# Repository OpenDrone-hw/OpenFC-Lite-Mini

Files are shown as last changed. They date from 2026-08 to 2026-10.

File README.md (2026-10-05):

# OpenFC-Lite-Mini

Open source Betaflight flight controller built on the RP2354A, 20 x 20 mm
mounting pattern, part of the incutec OpenDrone line.

<p>
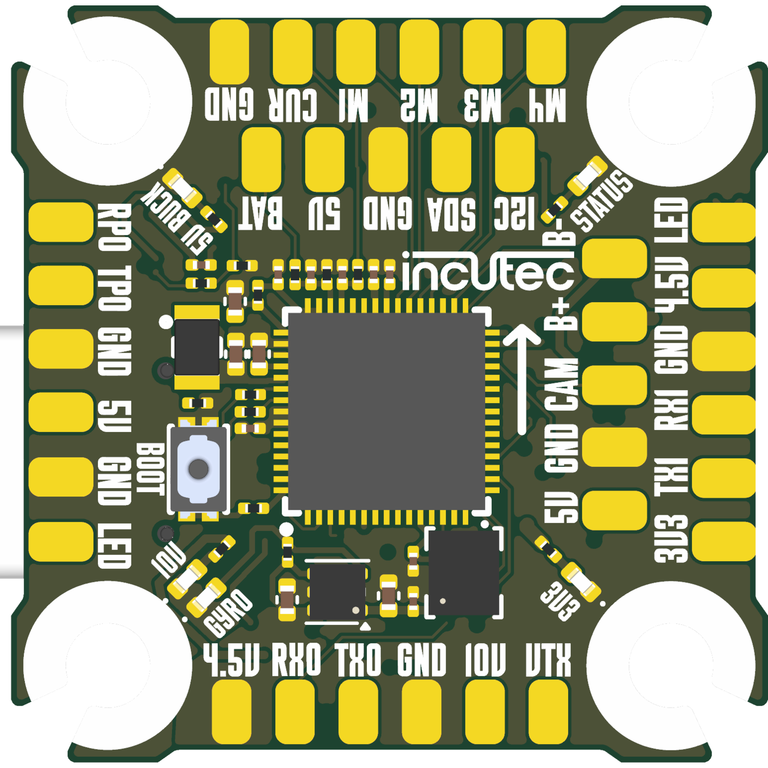
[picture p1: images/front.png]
OpenFC-Lite-Mini top

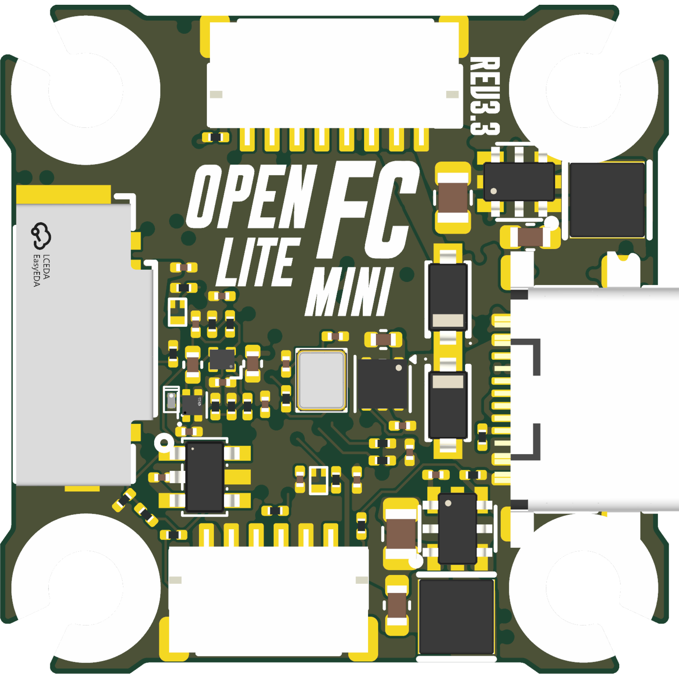
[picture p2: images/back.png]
OpenFC-Lite-Mini bottom

</p>







## Specifications

| | |
|---|---|
| Firmware | Betaflight |
| MCU | RP2354A |
| IMU | BMI270 |
| Barometer | None |
| Blackbox | microSD |
| OSD | Analog and digital |
| UARTs | 3 |
| Motor outputs | 4x DShot, bidirectional |
| RX | External, CRSF or SBUS |
| Input | 3-6S* LiPo (9.0-25.2 V) |
| BEC | 10 V switchable + 5 V always-on, 3 A |
| Current sense | Yes |
| USB | USB-C |
| Mounting | 20 x 20 mm, 3.0 mm holes |
| Dimensions | 26.9 x 26.9 mm |
| PCB | 6-layer, 1.6 mm |

* Also runs on 2S; the 10 V VTX output then follows the battery voltage instead of holding 10 V.

Technical write-up, part list and layout constraints: [AGENTS.md](AGENTS.md).

## In the line

What pairs with what, and what is available:
[opendrone.be](https://opendrone.be).

## Contributing

See [CONTRIBUTING.md](CONTRIBUTING.md).

## License

Hardware licensed under [CERN-OHL-S-2.0](https://ohwr.org/cern_ohl_s_v2.txt),
see [LICENSE](LICENSE).

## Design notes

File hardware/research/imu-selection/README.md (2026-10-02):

# IMU Selection Investigation: OpenFC-Lite-Mini Rev 2

**Superseded.** Rev 1 decision record, kept as history. The current IMU is the Bosch
BMI270 (U9), per the [README](../../../README.md) and [AGENTS.md](../../../AGENTS.md).

**Status:** superseded · **Started:** 2026-06-02

The Rev 1 IMU (ST **LSM6DSV16XTR**) is populated for development only. The Betaflight
team considers it unflyable; bench/flight data agrees. This folder collects datasheets
and test evidence to pick the **Rev 2 IMU**.

The footprint and its ST/TDK compatibility are described in
[`AGENTS.md`](../../../AGENTS.md) (Key parts section). IMU swap is a
part-population change once a part is chosen. Pin-by-pin verification against each
candidate family is in §8c below.

```
imu-selection/
├── README.md          ← this file (single source of truth for the investigation)
├── datasheets/        ← collected datasheets, named by part
└── (add scope captures, logs, FFTs here as they come in)
```

---

## 1. Hard requirements

| # | Requirement | Why |
|---|---|---|
| R1 | **Betaflight driver on current master** | No driver = no flyable firmware. Authoritative list below. |
| R2 | **Drops into LGA-14 (2.5×3 mm), pins 2/3 GND, 10/11 NC** | Existing footprint; pin-1 orientation must match. |
| R3 | **Flyable**: low in-band gyro noise, robust to electrical + vibration noise | The whole reason DSV16X is being replaced. |
| R4 | **Sourceable at volume** | Selling the board. |
| R5 | **Low cost**, to keep the "Lite" price point | The IMU is a large share of BOM cost. |
| R6 | **VDDIO works at 1.8 V analog / 3.3 V IO** | Board runs IMU off +1.8V_GYRO (U6 NCV8187) + 3.3V IO. |

A part failing R1 or R2 is out unless someone commits to adding the driver / reworking the
footprint.

---

## 2. Betaflight supported-IMU list (authoritative)

From `drivers/accgyro/accgyro.h` (`gyroHardware_e`) + `sensors/acceleration.h` on current
master. **Only these have flyable drivers today.**

- **InvenSense MPU:** MPU6000, MPU6050, MPU6500, MPU9250
- **InvenSense ICM-206xx:** ICM20601, ICM20602, ICM20608G, ICM20649, ICM20689
- **InvenSense ICM-426xx / 40609:** ICM42605, **ICM42688P**, **ICM42622P**, ICM42686P, ICM40609D
- **InvenSense IIM industrial (426xx driver):** IIM42652, IIM42653
- **InvenSense ICM-456xx:** ICM45605, **ICM45686**
- **Bosch:** BMI160, **BMI270**
- **ST:** LSM6DSO, **LSM6DSV16X**, **LSM6DSK320X**, L3GD20 (gyro-only)
- **Virtual:** SITL/HITL

**NOT on master (would need a driver):** ICM-56686 (RPi is adding it, not merged),
BMI323, BMI088, ICM-42670-P, LSM6DSV320X (the *V* high-g, ≠ the *K*).

---

## 3. Candidate matrix

"BF" = on master. Footprint column
flags anything that isn't a clean drop-in.

| Part | BF | Footprint | Gyro noise mdps/√Hz | Verdict |
|---|---|---|---|---|
| **ICM-42688-P** | ✓ king | LGA-14 2.5×3 ✓ | **2.8** | Best-flying, high cost |
| **ICM-42622P** | ✓ | LGA-14 ✓ | ~2.8 (class) | strong reports |
| **IIM-42652** | ✓ | LGA-14 ✓ | 3.8 | Industrial temp, high cost |
| **ICM-45686** | ✓ | **LGA-14 3×2.5** ⚠ rotated | ~ | Newer; verify pin-1, high cost |
| **ICM-45605** | ✓ | LGA-14 | - | budget 456xx |
| **ICM-42605** | ✓ | LGA-14 2.5×3 ✓ | (class) | **Supported: solid fallback** |
| **BMI270** | ✓ | LGA-14 2.5×3 | 7 (perf) | **Low cost, only AC-PSRR spec'd** ⚠ verify Bosch pinout |
| **LSM6DSO** | ✓ | LGA-14 2.5×3 ✓ | (older) | low cost, older gen |
| **LSM6DSV16X** | ✓ | LGA-14 2.5×3 ✓ | 2.8 | **Rev 1 part: unflyable, replaced** |
| **LSM6DSK320X** | ✓ | LGA-14 2.5×3 ✓ | **3.8** | BF/STM target; **not orderable**, samples gated |
| ICM-56686 | ✗ | LGA-14 2.5×3 | 2.9 | No BF driver yet (RPi adding); 29.3kHz MEMS |
| BMI323 | ✗ | LGA-14 | - | No BF driver; Bosch filters undocumented |
| BMI088 | ✗ | **LGA-16 3×4.5** ✗ | 14 | No driver, wrong footprint, 2.4V floor: out |
| LSM6DSV320X | ✗ | LGA-14L | - | *V* variant, no BF driver (≠ DSK) |

---

## 4. Datasheet spec comparison

Mined from the PDFs in `datasheets/`. "n/s" = not specified in datasheet.

| Spec | ICM-42688-P | IIM-42652 | ICM-56686 | BMI270 | BMI088 | LSM6DSV16X | LSM6DSK320X |
|---|---|---|---|---|---|---|---|
| Gyro noise (mdps/√Hz) | **2.8** | 3.8 | 2.9 / 2.5(20b) | 7 / 10 | 14 | **2.8** | 3.8 |
| Accel noise (µg/√Hz) | 65/70 | 70 | 55/70 | 160 | 190 | 60/100 | 60/100/1000(hi-g) |
| Gyro FS max (dps) | 2000 | 2000 | 4000 | 2000 | 2000 | 4000 | 4000 |
| Accel FS max (g) | 16 | 16 | 32 | 16 | 24 | 16 | **320** (hi-g) |
| Max gyro ODR (kHz) | 8 | 8 | 6.4 | 6.4 | 2 | 7.68 | 7.68 |
| MEMS resonant freq | n/s | n/s | **29.3 kHz** | n/s | n/s | n/s | n/s |
| Anti-alias filter | AAF 42-3979Hz + notch | AAF 42-3979Hz | AAF+LPF | LPF | LPF 5-532Hz | analog AAF + LPF1 | analog AAF + LPF1 |
| VDD / VDDIO (V) | 1.71-3.6 / 1.71-3.6 | 1.71-3.6 / 1.71-3.6 | 1.71-3.6 / 1.08-3.6 | 1.71-3.6 / 1.2-3.6 | **2.4**-3.6 / 1.2 | 1.71-3.6 / 1.08 | 1.71-3.6 / 1.08 |
| SPI max (MHz) | 24 | 24 | 24 | 10 | 10 | 10 | 10 |
| Package | LGA-14 2.5×3 | LGA-14 2.5×3 | LGA-14 2.5×3 | LGA-14 2.5×3 | **LGA-16 3×4.5** | LGA-14 2.5×3 | LGA-14 2.5×3 |
| **PSRR / supply-noise spec** | 10mVpp tol. | 10mVpp tol. | 10mV typ/50max, to 1MHz | **AC PSRR: gyro 0.40dps/50mV, accel <8mg/50mV, 100Hz-1MHz** | DC drift only | **n/s** | **n/s** |
| CLKIN | **yes** 31-50k | **yes** | **yes** 20-40k | no | no | no | no |

### Headline findings

1. **The DSK320X is NOT a quieter gyro than the DSV16X.** On paper it's *worse*: 3.8 vs
   2.8 mdps/√Hz, identical accel noise. Neither ST datasheet documents a MEMS resonant-freq
   change or sensor-level vibration-immunity improvement. The DSK's only vibration-relevant
   edge is the **±320 g high-g channel** (clip resistance under hard impact) + quad-channel
   UI/EIS/OIS/high-g filtering, **not** a lower-noise or more supply-robust gyro core. This
   directly contradicts the framing that the DSK "fixes the noise": the fix, if real, is in
   MEMS hardware ST does not document, or in the high-g anti-clip path.

2. **Neither ST part specs any PSRR / supply-noise rejection.** This is the standout gap
   versus the observed failure (sensitivity to *electrical* noise). You cannot design a
   supply-ripple budget against a number that doesn't exist.

3. **BMI270 is the only candidate with a frequency-resolved AC PSRR:** gyro 0.40 dps per
   50 mV ripple (100 Hz-1 MHz). InvenSense parts at least give a max-tolerable-ripple (10 mV).
   If supply-coupled noise is the real culprit, Bosch + InvenSense give you a spec; ST gives
   you nothing.

4. **Vibration-aliasing immunity:** ICM-56686 is the only part publishing a MEMS drive
   frequency (29.3 kHz, far above any propwash band, good anti-alias margin). BMI088 is the
   only one with explicit "drone/robotics vibration suppression + ±24 g anti-clip" language,
   but it's the worst on noise, wrong footprint, no driver. Out on R1/R2.

---

## 5. External input and flight data

### Betaflight-ecosystem consensus
- LSM6DSV16X is considered **unflyable**: "too sensitive to electrical noise." Tested on
  5+ FCs across brands, all unacceptable; it will not be approved for ecosystem hardware.
- **LSM6DSK320X** is the recommended successor, developed together with ST; mass
  production targeted **June 2026**. Described as worth waiting for, drop-in on the LSM16
  design.
- **ICM-42688 "still king"** but TDK supply is hard. **ICM-42622 also rated very highly.**
- **Bosch** BMI270: internal filters undocumented, "not great but cheap and works",
  pin-for-pin swappable later. Recommended only as a cheap interim.
- **Clone IMUs** (HXY ICM-42688P etc.) rejected on principle: unknown provenance.
- ⚠ Bias to note: Betaflight and ST have a working relationship, and ST has a commercial
  interest in the DSK320X winning the comparison. Weigh accordingly.

### Counter-argument: the failure may be PDN-specific
- This board's IMU supply is unusually good: **NCV8187 ~90 dB PSRR**, and running the IMU
  at **1.8 V** means a large LDO dropout → even better rejection. The board's electrical
  environment is likely *better* than the cheap FCs the DSV16X was condemned on, so those
  failures may be PCB/PDN-specific, not intrinsic to the part. (For comparison, at least
  one well-regarded reference design uses a ~75 dB PSRR IMU LDO, worse than ours.)
- DSK320X has **different MEMS hardware**. DSV320X is the *V* high-g variant.
- One proposed strategy: ship the Lite with **BMI270** (cheap, holds the price point) now;
  a premium board with a higher-end IMU later.

### Flight data: hover A/B against an ICM reference board
- Our board (DSV16X): **prefilter gyro shows ~20 dB more <100 Hz broadband noise** than an
  ICM reference board, on a *hover* test. Would need a hard detune to fly.
- Comparison is apples-to-apples: both FCs MCU-down, gyro-up → noise is **not** ESC-side.
- **Adding a cap on 5 V** often helps in this failure mode → points at supply-coupled noise.
- ⚠ Counter-datapoint: a 1408/3750kv/6S 3" test quad on DSV16X flew **perfectly** once a
  suitable tune/filter preset was applied, i.e. the issue may be tune/filtering, not raw
  sensor. Sample size 1. Worth resolving before committing.

### ICM-56686
- Betaflight support for the **ICM-56686** (positioned as an ICM-42688 alternative) is
  reportedly in development elsewhere; **no driver on master yet**. TDK cleared the
  datasheet for sharing → in `datasheets/`.

---

## 5b. What actually matters in FPV (not bench noise density)

FPV is not a clean environment: the gyro lives in heavy mechanical vibration (motors, props,
frame/arm resonances, often 0.5-4 kHz) plus ESC switching/EMI. **Bench noise density is nearly
the wrong figure of merit.** Proof: the DSV16X has the *best* noise density of every candidate
here (2.8 mdps/√Hz, tied with the 42688) and is still unflyable. Flyability is set by how the
part handles **out-of-band energy**, not its quiet-room floor:

1. **Vibration rectification / aliasing.** Out-of-band vibration (kHz) folds into the control
   band as a DC offset shift + low-frequency broadband, exactly the **<100 Hz broadband**
   signature in the hover A/B data (§5). Governed by the **MEMS drive/sense resonant frequency** and
   the **analog anti-alias filter ahead of the ADC** (not the digital LPF, which is too late).
   → ICM-56686 is the only part publishing its resonant freq (29.3 kHz, big margin). ST parts
   publish neither resonant freq nor rectification behavior.
2. **Clipping headroom under vibration.** Instantaneous rate/accel spikes that exceed FS clip,
   and clipping rectifies into DC + harmonics. This, not "more range", is why DSK320X has a
   ±320 g accel channel and BMI088 has ±24 g. A ±16 g accel can saturate on a rough quad.
3. **Supply / EMI rejection.** ESC switching coupling into a part with unbounded PSRR. ST specs
   none; BMI270 specs AC PSRR; InvenSense specs a max tolerable ripple.

**Consequence for this investigation:** rank candidates on (1) anti-alias/resonant-freq margin,
(2) clip headroom, (3) PSRR, and above all on **empirical flight/blackbox data**, since
datasheets barely document any of the three. The noise-density column in §4 is informational,
not a selection criterion. This is why BF qualifies gyros by flying them, and why a
worse-on-paper part (DSK320X) can outfly the DSV16X.

## 5c. Prior diagnostic campaign, firmware A/B builds (sister board)

A documented DSV16X diagnostic effort already ran on a sister board carrying the same
LSM6DSV16XTR (late April 2026): one firmware variant per hypothesis, each with a blackbox
test plan. Results live in the blackbox logs, still to be recovered.

| Firmware change | Hypothesis | Symptom targeted |
|---|---|---|
| DRDY PULSED→LATCHED | RP2350 @150 MHz EXTI+SPI-DMA latency exceeds the **75 µs DRDY pulse** under heavy IRQ load (PIO DSHOT/UART, SD blackbox) → missed gyro samples → sample-rate drift | **200 Hz oscillation under throttle, fine at hover** |
| accel LPF2 250 Hz→~22 Hz | motor-harmonic vibration >250 Hz leaks into accel → corrupts IMU-fusion gravity vector | **"gravity-vector wandering" in ANGLE mode** |
| on-board chirp PID identifier (`USE_SYSID`) | (tooling) `sysid raw` emits a versioned **FRF CSV** for frequency-response analysis | n/a |

**Why this matters for IMU selection:** the two leading in-house hypotheses for the DSV16X
misbehaviour are **firmware/platform**, not "bad MEMS":
1. a **DRDY timing bug specific to RP2350 under load** (missed samples → the 200 Hz throttle
   oscillation), and
2. an **accel-filter config** leaking vibration into fusion (gravity wander).

Both are fixable without changing the sensor. This strongly reinforces §6: the part may be
partly mis-integrated on RP2350, not intrinsically unflyable. Note these symptoms (200 Hz
under-throttle oscillation; gravity wander) are **distinct from the hover A/B** result (<100 Hz
broadband prefilter noise at hover), so there may be ≥2 independent problems, only one of
which the sensor swap would fix.

The blackbox logs from these builds plus their baseline, and the `sysid raw` FRF CSV, are
the highest-value missing evidence (see §8).

## 5d. RESOLVED on the sister board, empirical

The firmware A/B campaign concluded the DSV16X problem is **not firmware-fixable**: it's a MEMS
hardware property. The sister board's firmware config records the swap rationale: the
LSM6DSV16XTR was found to have a **MEMS resonance vulnerability in the ~25 kRPM motor band**
on that airframe (the internal gyro **saturating from acoustic/vibration energy at the
resonator's drive frequency, producing bursts of false rotation reads up to chip full-scale
±2000 dps**). Swapping to the **ICM-42688-P** (drop-in pin-compatible, confirmed by multiple
BF targets that support both chips on the same pads) **eliminated the resonance issue**, and
the sister board's next PCB revision is designed with the ICM-42688-P only.

**What this settles, and what it does NOT.**

Settled: **swapping to ICM-42688-P made the board flyable**, and the sister board's next
revision standardizes on it. That's a solid empirical result for *part selection*.

NOT settled: the **root cause**. The "MEMS resonance in the ~25 kRPM band" wording is a
*hypothesis writeup*, not a measured result, and it does not survive scrutiny as a single cause:

- **The hover A/B noise is <100 Hz broadband at HOVER** (low RPM/vibration). A high-RPM resonance
  should be throttle-dependent and absent at hover, which is what the *diag build* describes
  ("200 Hz under throttle, fine at hover"). So there are **≥2 distinct symptoms**, not one.
- **"~25 kRPM band" is physically shaky:** 25 kRPM ≈ 417 Hz fundamental; a MEMS gyro drive
  resonance is ~20-25 **kHz** (~50× higher). 417 Hz vibration doesn't excite a 20 kHz drive
  mode directly. The plausible mechanism is **aliasing** (out-of-band energy folding in through
  an inadequate AAF), a filtering/architecture issue, not "resonator saturation."
- **"5 V cap helps" + the "electrical noise" reports + ST publishing no PSRR** → an independent
  **supply/PSRR** contributor.
- **A tune/filter preset made one build fly perfectly** → **tune/filtering** is a large lever; a
  hard MEMS-saturation defect wouldn't yield to a preset.
- **The ICM swap is a confounded experiment:** it changed sensor + driver maturity + AAF/notch
  behavior + CLKIN jitter removal simultaneously. It does **not** isolate resonance as the cause.

**Working model: multi-causal**, at least: (1) anti-alias/filtering inadequacy → aliased
broadband; (2) supply/PSRR sensitivity; (3) RP2350 DRDY/sample-timing under load; (4) MEMS
resonance/clipping at high vibration; (5) driver/tune immaturity. The ICM-42688-P is better on
*several* of these at once, which is why it works, but the dominant factor is not isolated.

**Consequence for selection:** because the win is partly filtering/driver/PSRR (not purely a
MEMS-element property), a same-family ICM-42605 is a *strong* bet (shares AAF+notch+driver), and
the **BMI270's real AC-PSRR spec regains relevance** if supply coupling is a major contributor.
Only the actual logs/FFT (hover vs throttle, ± a supply-ripple injection test) can decompose it.

## 6. Working hypothesis

The DSV16X's in-flight noise is most plausibly **supply/electrical-coupling + tune**, not a
raw-noise-density deficit (its density spec is best-in-class, tied with the 42688). Evidence:
- 20 dB excess is **broadband <100 Hz** = classic aliased/rectified noise, not white density.
- "Adding a cap on 5 V helps" + "sensitive to electrical noise" = PDN/supply path.
- A good preset made it fly fine on our board (better PDN than the FCs BF condemned).
- ST publishes **no PSRR**, so the part's supply robustness is genuinely unknown/unbounded,
  consistent with it being fragile on noisy boards even if fine on a clean one.

This means the decision is partly **political** (BF approval / the 180-brand ecosystem rejects
DSV16X regardless of our data) and partly **technical** (what actually flies clean on *our*
PDN). Those can have different answers.

---

## 7. Decision options

**Reframed by §5d:** the failure is MEMS resonance saturation, and **ICM-42688-P is the
empirically proven fix** on the sister board. The 426xx family shares the same gyro sense-element
architecture, so a cheaper family member is the *likely*, but not yet proven, way to keep the
fix at a Lite price. A different-MEMS part (BMI270) is now a real risk, not a safe interim.

- **A: ICM-42688-P (proven). ← lowest technical risk.** The exact part that eliminated the
  resonance on the sister board, whose next revision standardizes on it. Drop-in (§4), uses wired CLKIN (GPIO15).
  **Cost is the only problem:** too expensive for the "Lite"
  price point. Right call for a *premium* OpenFC; painful for Lite.
- **B: ICM-42605 (cheap same-family bet). ← leading for Lite (2026-06-02).** Same 426xx gyro
  architecture as the 42688 → *most likely* shares the resonance immunity (same sense element,
  different binning/noise grade). BF-supported, lower cost, clean
  2.5×3 footprint, uses the wired CLKIN. **Risk: the resonance immunity is not yet confirmed on
  the 42605 specifically**: verify by flying it (it shares the 42688 driver, so it's a config
  one-liner: `USE_GYRO_SPI_ICM42605`). If it holds, this is the answer for Lite.
- **C: ICM-42622P** (highly rated, same family), but out on cost and availability
  at the time.
- **D: BMI270 (cheapest, now higher risk).** Lowest cost, BF-supported, footprint
  drop-in (§7b), only candidate with a real AC-PSRR spec. **But:** different Bosch MEMS: we now
  know the DSV16X failure was MEMS-resonance, and there is **no evidence BMI270 survives this
  airframe's resonance band**. Bench noise density (7) is irrelevant (§5b); the resonance
  question is not. Only choose if 42605 also fails and price dominates, and flight-test it
  against the same airframe first.
- **E: DSK320X**, BF/STM blessed, drop-in, but **not orderable** (samples gated), and per §4
  not a lower-noise gyro. Track for the premium SKU; not actionable for Rev 2 now.
- **F: Two-SKU strategy.** Premium OpenFC = ICM-42688-P (proven). Lite = ICM-42605 if it flies
  clean, else BMI270 as the cost-floor fallback. Aligns the premium board with the sister board's next revision.

**Recommendation:** Lite-Mini Rev 2 → **ICM-42605** (lower cost, same family as the proven
fix, wired CLKIN usable), with **ICM-42688-P** as the drop-in premium/no-compromise option on the
identical footprint. **Flight-test the 42605 against a ~25 kRPM-band airframe before committing**:
that's the one open risk, and it's cheap to close.

---

## 7b. BMI270 footprint verification (DONE 2026-06-02)

Checked BMI270 pinout vs the actual board net on U9 (netlist export of `OpenFC.kicad_sch`).
Board pins wired for the LSM6DSV16X: 1 MISO, 2 GND, 3 GND, 4 INT, 5 +3.3V, 6 GND, 7 GND,
8 +1.8V_GYRO, 9 CLKIN(GPIO15), 10 NC, 11 NC, 12 CS, 13 SCK, 14 MOSI.

**BMI270 is a drop-in, with two caveats:**
- **Pins 2/3 = ASDx/ASCx (aux/OIS), hard-grounded on our board.** Bosch documents "VDDIO or
  DNC", *not* GND. The shared 20×20 FC footprint grounds these and BMI270 ships on it across
  many BF boards (works empirically), but it is **outside Bosch's stated spec**: verify on a
  sample; worst case a DNC cut on 2/3.
- **Pin 9 = our CLKIN net (GPIO15).** On BMI270 pin 9 is INT2 (no clock input). No regression
  (ST part also has no CLKIN); just don't drive a clock on GPIO15 in firmware. Aligns with the
  Rev 2 "drop CLKIN" plan.
- All other pins (SPI 1/12/13/14, VDD 8 @1.8V, VDDIO 5 @3.3V, INT1 4, GND 6/7, NC 10/11) match 1:1.

## 8. Verification state

- **Verified:** BMI270 LGA-14 fits the existing footprint. Pins 2/3 remain an
  out-of-spec, field-proven grounding caveat; pin 9 maps CLKIN to unused INT2.
- **Not evidenced here:** ICM-45686 land-pattern orientation; availability of
  ICM-42622P or LSM6DSK320X; and ICM-56686 driver maturity.
- **Design-dependent:** CLKIN is useful for the listed TDK parts and unused by
  the ST and Bosch candidates. Its routing follows the selected IMU.
- **Not present in this repository:** the source FFT/blackbox data behind the
  hover comparison, a cross-board PDN comparison, and measured 1.8 V rail
  compatibility for every candidate. Claims depending on those data are not
  treated as verified.

---

## 8b. Log comparison: PIDtoolbox method + first run (2026-06-02)

**How PIDtoolbox (PTB) works** (Brian White / bw1129, MATLAB or compiled standalone):
decodes BF blackbox → modules: **Spectral Analyzer** (gyro/dterm PSD in dB + **Freq×Throttle
spectrogram**), **Step Response** (setpoint→gyro deconvolution), time-domain plots.
- Set **`debug_mode = GYRO_SCALED`** so unfiltered gyro is logged (PTB then shows *gyro prefilt*
  vs *gyro*, and computes filter phase latency). **Modern BF (2026.x) logs `gyroUnfilt[]`
  natively** regardless of debug_mode, our logs have it, so prefilter analysis works anyway.
- Log at **2 kHz** (spectrograms reach ~1 kHz). Fly **throttle sweeps** (idle→full over 5-10 s, ×2-3).
- **Reading Freq×Throttle:** diagonal line rising with throttle = **motor noise (tracks RPM)**;
  horizontal line at fixed Hz = **frame resonance or electrical (throttle-independent)**;
  <20 Hz = real craft movement (ignore for noise); 20-100 Hz should be quiet (propwash/tune).
- **Bad-gyro test:** one axis much noisier <200 Hz; rotate FC 90°: if the noisy axis follows, gyro suspect.

**Why prefilter (`gyroUnfilt`) is the right signal here:** it's the raw sensor before BF's filter
stack, so comparing it removes the filter-tune confound and isolates the *sensor*.

**Reproduce without MATLAB:** `analysis/compare_gyro.py LOG_A.csv LOG_B.csv labelA labelB`
(numpy/scipy/matplotlib) emits `psd_overlay.png`, `spectrogram_<label>_<axis>.png`, and a
band-RMS table. PTB GUI crashed on macOS 2026-06-02; this is the fallback + it's repo-committed.

**First run: LOG00083 vs LOG00090** (both built for OPENFC_ECO, the OpenFC-ECO-era firmware target since superseded by OPENFC_LITE_MINI_RP2350A; BF 2026.6.0-alpha, 8 kHz loop, logged
≈1.88 kHz → 940 Hz Nyquist). **Inconclusive on sensor, the pair is not controlled:**
- LOG83 = 135 s full sweep, gyro LPF off; LOG90 = **only 6 s**, sparse throttle, dyn-LPF 250/500.
- **Which log is which sensor is unknown** (BF header doesn't name the gyro; same firmware hash
  runs either chip via autodetect). **The LOG#→sensor mapping must be recovered from test notes.**
- Prefilter PSD floors **nearly overlap** in the noise-dominated bands (motor hump ~200-400 Hz,
  >400 Hz). The big 0-20 Hz "RMS" differences are **flight movement, not noise** (135 s aggressive
  vs 6 s), not a sensor signal.
- LOG83 spectrogram = **clean, healthy**: motor band tracks throttle, no fixed horizontal lines,
  no saturation bursts. LOG90 looks hotter in 200-500 Hz but is too short/sparse to trust.

**Verdict:** these two logs cannot decide DSV16X vs ICM. Need a **matched pair**: same craft,
both throttle sweeps, ≥30 s each, same filter config (or compare prefilt only), and a known
LOG#→sensor map. Then the Freq×Throttle + prefilt-PSD overlay will show whether the DSV16X has
(a) RPM-tracking diagonal excess (vibration/alias), (b) fixed-Hz lines at idle (electrical/PSRR),
or (c) saturation bursts (resonance/clipping), decomposing §5d's multi-causal model.

## 8c. Universal drop-in verification (footprint + nets, working tree 2026-06-03)

Footprint `lib:LGA-14_L3.0-W2.5-P0.50-BR`. U9 net map (current schematic): 1 MISO · 2 GND ·
3 GND · 4 INT · 5 +3.3V(VDDIO) · 6 GND · 7 GND · 8 +1.8V_GYRO(VDD) · 9 CLKIN(GPIO15) ·
10 NC · 11 NC · 12 CS · 13 SCK · 14 MOSI. Checked against datasheet pinouts:

| Pin | Board net | ST LSM6D* (DSV16X / DSK320X / DSO) | TDK ICM-426xx / IIM-426xx | Bosch BMI270 |
|---|---|---|---|---|
| 1 | MISO | SDO ✓ | AP_SDO ✓ | SDO ✓ |
| **2** | **GND** | SDx: *"VDDIO or GND"* ✓ | RESV: *NC/GND* ✓ | ASDx (aux, unused→input): table prefers *VDDIO/DNC*, GND benign ✓ |
| **3** | **GND** | SCx: *"VDDIO or GND"* ✓ | RESV: *NC/GND* ✓ | ASCx (aux, unused→input): GND benign ✓ |
| 4 | INT | INT1 ✓ | INT1 ✓ | INT1 ✓ |
| 5 | +3.3V | VDDIO ✓ | VDDIO ✓ | VDDIO ✓ |
| 6 | GND | GND ✓ | GND ✓ | GNDIO ✓ |
| 7 | GND | GND ✓ | RESV→GND ✓ | GND ✓ |
| 8 | +1.8V | VDD ✓ | VDD ✓ | VDD ✓ |
| 9 | CLKIN | INT2 (idle, ok)¹ | INT2/FSYNC/**CLKIN** ✓ (uses it) | INT2 (idle, ok)¹ |
| 10 | NC | OCS_Aux NC ✓ | RESV NC ✓ | OCSB DNC ✓ |
| 11 | NC | SDO_Aux NC ✓ | RESV NC ✓ | OSDO DNC ✓ |
| 12 | CS | CS ✓ | AP_CS ✓ | CSB ✓ |
| 13 | SCK | SCL/SCLK ✓ | AP_SCLK ✓ | SCK ✓ |
| 14 | MOSI | SDA/SDI ✓ | AP_SDI ✓ | SDI ✓ |

¹ pin 9 = INT2 on ST/Bosch; harmless as long as firmware does not drive a clock on GPIO15.

### Verdict: pins 2/3 at GND are fine for all; footprint is universal
The board grounds pins 2/3. For an **unused** aux interface this is correct/benign across all families:
- **ST LSM6D\*** (DSV16X / DSK320X / DSO): datasheet sanctions pins 2/3 → "VDDIO **or GND**". ✓
- **TDK ICM-426xx/IIM and ICM-456xx/56xx-gen** (confirmed from ICM-56686 pinout: pins 2/3/10/11 =
  RESV/AUX1, pin 9 = INT2/FSYNC/CLKIN, same universal layout): RESV = "NC **or GND**". ✓
- **Bosch BMI270: GND is safe (mechanism verified in datasheet, 2026-06-03):** aux/OIS is disabled
  by default (`PWR_CTRL.aux_en=0`; BF never enables it for a bare gyro), so ASDx/ASCx are **high-Z
  inputs**: nothing drives them, GND = no contention. The only "pull-up" is a *configurable* internal
  pull-up on ASDA (`AUX_IF_TRIM.asda_pupsel`: off/40k/10k/2k) used for the aux-I2C SDA line; inactive
  when aux is off (worst case a 40k pull → ~80 µA to GND, harmless). Bosch's "VDDIO or DNC" is
  conservative guidance for the aux-*enabled* case; it does **not** mean GND damages the part. Bosch's
  own power-off note even says interface pins "must be kept close to GNDIO potential." The *only*
  failure case is firmware enabling the aux **I2C master** (ASCx becomes a driven clock → GND short),
  which BF does not do. **GND is the correct universal tie** (VDDIO fails TDK RESV; NC fails ST's
  "needs a level"). One firmware caveat: never enable the BMI270 aux interface.

**So the footprint is a genuine universal drop-in** for every ST LSM6D\*, every TDK ICM-426xx/IIM,
the 456xx/56xx-generation TDK parts, and the BMI270: **no schematic change needed.**

### Open item
- **ICM-45686/45605 physical orientation:** pin *functions* match (per 56686), but the 45686 is listed
  as LGA-14 **3×2.5** vs our 2.5×3 → check body/pin-1 rotation against the footprint before
  committing. (Functional pinout is fine; this is purely a package-outline check.)
- **Keep pin 9 (GPIO15→CLKIN) wired**: revisit the Rev 2 "drop CLKIN" note. Harmless for ST/Bosch
  (INT2, idle), and gives TDK 426xx/456xx sample-clock jitter removal (relevant to the noise work).

## 9. Datasheet index

| File | Part | Class | BF driver |
|---|---|---|---|
| `datasheets/ICM-42688-P.pdf` | TDK ICM-42688-P | consumer flagship | ✓ |
| `datasheets/IIM-42652.pdf` | TDK IIM-42652 | industrial-temp 426xx | ✓ |
| `datasheets/ICM-56686.pdf` | TDK ICM-56686 | AR/VR-OIS (29.3kHz MEMS) | ✗ (RPi adding) |
| `datasheets/BMI270.pdf` | Bosch BMI270 | consumer/wearable | ✓ |
| `datasheets/BMI088.pdf` | Bosch BMI088 | drone/robotics high-vib | ✗ |
| `datasheets/LSM6DSV16X.pdf` | ST LSM6DSV16X | consumer/OIS (Rev 1 part) | ✓ |
| `datasheets/LSM6DSK320X_rev0.1.pdf` | ST LSM6DSK320X | high-end dual-accel | ✓ |

**Still to collect:** ICM-42622P, ICM-42605, ICM-45686, ICM-45605, LSM6DSO datasheets.

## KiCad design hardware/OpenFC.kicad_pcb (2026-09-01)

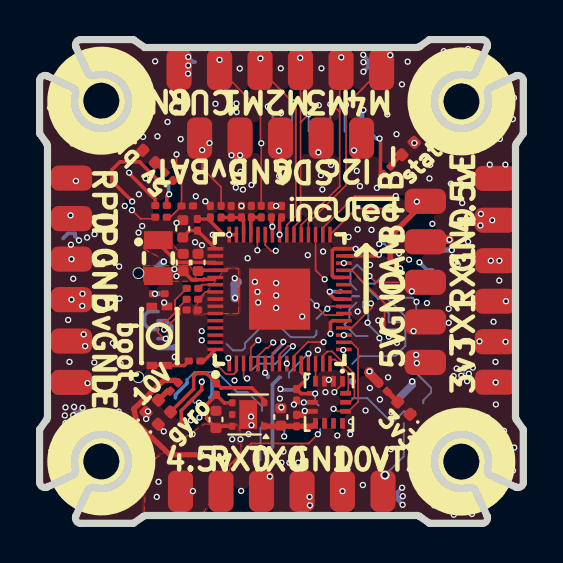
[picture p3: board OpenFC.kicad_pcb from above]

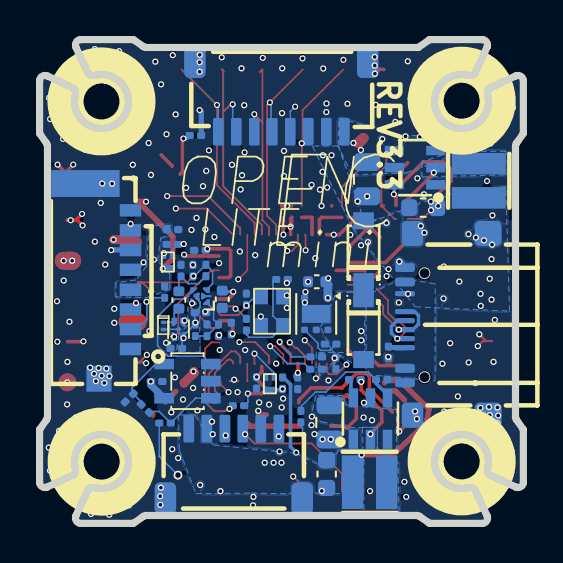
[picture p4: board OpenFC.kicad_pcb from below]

Board: 6 copper layers, 26.9 x 26.9 mm, 131 parts (58 on the bottom side), 75 nets.

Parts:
C1, C3, C4, C5, C7, C8, C9, C11, C12, C13, C22, C26, C27, C32, C35, C36, C39, C41, C42, C43: 100n; C_0201_0603Metric
C6, C10: 20p; C_0201_0603Metric
C24, C25: 4.7uF 50v; C_0805_2012Metric
C28, C29: 22uF; C_0603_1608Metric
C31, C37, C44, C45, C46: 4.7uF; C_0402_1005Metric
C33, C34: 22uF; C_0402_1005Metric
C38: 470p; C_0201_0603Metric
C40: 1uF; C_0402_1005Metric
Card1: TF-021B-H265; TF-SMD_TF-021B-H265
D2: LED_1_Blue; LED_0402_1005Metric
D4, D5, D7, D8: LED_1_Green; LED_0402_1005Metric
D6, D10: DSK24; SOD-123_L2.8-W1.8-LS3.7-RD
D9: SDM02U30LP3-7B; X3-DFN0603-2_L0.6-W0.3-RD
J5, J8, J10, J12, J14, J15, J17, J18, J20, J21, J22, J24, J25, J26, J27, J28, J29, J30, J31, J32, J33, J34, J35, J37, J39, J40, J41, J42, J43, J44, J45, J46, J48, J49: 5V; small_pad
L2, L3: XRTC303020D4R7MBCA; IND-SMD_L3.0-W3.0_AFE303020S
L4: AOTA-B201610S3R3-101-T; IND-SMD_L2.0-W1.6_AOTA-B201610S3R3-101-T
P1: SM08B-SRSS-TB(LF)(SN); CONN-TH_SM08B-SRSS-TB-LF-SN
Q5, Q6: AP1606; DFN-3L_L1.0-W0.6-P0.65-BR
R1, R23, R29, R31: 100k; R_0201_0603Metric
R2, R38, R39, R49: 10k; R_0201_0603Metric
R3, R4, R6, R7: 5.1k; R_0201_0603Metric
R5, R9: 1k; R_0201_0603Metric
R15, R24, R37: 30R; R_0201_0603Metric
R30, R34: 6.49k; R_0201_0603Metric
R32: 13.7k; R_0201_0603Metric
R33: 7.5k; R_0201_0603Metric
R36, R46, R47: 510R; R_0201_0603Metric
R41, R48, R52, R53: 75R; R_0201_0603Metric
R42: 3.9k; R_0201_0603Metric
R43: 12k; R_0201_0603Metric
R44: 1.4k; R_0201_0603Metric
R45: 680R; R_0201_0603Metric
R50, R51: 2.4k; R_0201_0603Metric
U1: COS8051SOT; SOT-23-5_L3.0-W1.7-P0.95-LS2.8-BR
U2: TLV7031DPWR; X2SON-4_L0.8-W0.8-P0.48-TL-A
U3, U4: LMR51430YFDDCR; SOT-23-6_L2.9-W1.6-P0.95-LS2.9-BL
U7: LP5912-3.3DRVR; WSON-6-1EP_2x2mm_P0.65mm_EP1x1.6mm
U8: SM06B-SRSS-TB(LF)(SN); CONN-SMD_SM06B-SRSS-TB-LF-SN
U9: BMI270; LGA-14_L3.0-W2.5-P0.50-BR
U10: RP2354A; QFN-60_L7.0-W7.0-P0.40-TL-EP3.4
U11: TS2306A 240GF MSM 9_C2976675; SW-SMD_4P-L3.0-W2.0-P0.85-LS3.5
U12: LP5912-1.8DRVR; WSON-6-1EP_2x2mm_P0.65mm_EP1x1.6mm_ThermalVias
U18: SN74LVC1G3157DTBR; X2SON-6_L1.0-W0.8-BL
USB1: TYPE-C 16P QTWT; USB-TYPE-C-SMD_TYPE-C-16P-QTWT
X1: XTM25012000JT00351001; CRYSTAL-SMD_4P-L2.5-W2.0-BL-A

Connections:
+1.1V: C1.1, C3.1, C37.1, C46.1, L4.1, U10.6 (DVDD), U10.23 (DVDD), U10.39 (DVDD), U10.50 (VREG_FB)
+1.8V_GYRO: C33.1, C35.1, U9.8 (Vdd), U12.1 (OUT)
+3.3V: C5.1, C7.1, C8.1, C9.1, C11.1, C12.1, C13.1, C34.1, C36.1, C39.1, C41.1, C42.1, C43.1, C45.1, Card1.4 (VDD), J28.1 (Pin_1_1), R6.1, R7.1, R15.1, R36.1, R39.1, R43.2, R49.2, U1.5 (+VS), U2.2 (VCC), U7.1 (OUT), U9.5 (Vdd_IO), U10.1 (IOVDD), U10.11 (IOVDD), U10.20 (IOVDD), U10.26 (RUN), U10.30 (IOVDD), U10.38 (IOVDD), U10.44 (ADC_AVDD), U10.45 (IOVDD), U10.49 (VREG_VIN), U10.53 (USB_OTP_VDD), U10.54 (QSPI_IOVDD), U18.5 (VCC)
+4v5: C31.1, C32.1, D6.1 (K), D10.1 (K), J5.1 (Pin_1_1), J40.1 (Pin_1_1), R34.1, U7.4 (EN), U7.6 (IN), U12.4 (EN), U12.6 (IN)
+5V: C29.1, D6.2 (A), J17.1 (Pin_1_1), J22.1 (Pin_1_1), J25.1 (Pin_1_1), J30.1 (Pin_1_1), L3.2, R31.2, R50.1, R51.1
+5V_USB: D10.2 (A), USB1.A4 (VBUS), USB1.A9 (VBUS)
+10V: C28.1, J45.1 (Pin_1_1), L2.2, R29.2, R33.1, U8.1
+BATT: C24.1, C25.1, J29.1 (Pin_1_1), P1.1, R1.2, U3.3 (VIN), U4.3 (VIN), U4.5 (EN)
/BLACKBOX/FLASH_CS: Card1.2 (CD/DAT3), R39.2, U10.33 (GPIO21)
/BLACKBOX/SPI0.MISO: Card1.7 (DAT0), U10.32 (GPIO20)
/BLACKBOX/SPI0.MOSI: Card1.3 (CMD), U10.31 (GPIO19)
/BLACKBOX/SPI0.SCK: Card1.5 (CLX), U10.29 (GPIO18)
/IMU/CS: R49.1, U9.12 (CS), U10.17 (GPIO13)
/IMU/GYRO_INT: U9.4 (INT1), U10.13 (GPIO9)
/IMU/SPI1.MISO: U9.1 (SDO/SA0), U10.16 (GPIO12)
/IMU/SPI1.MOSI: U9.14 (SDA), U10.15 (GPIO11)
/IMU/SPI1.SCK: U9.13 (SCL), U10.14 (GPIO10)
/OSD/OSD_EN: U10.19 (GPIO15), U18.6 (S)
/OSD/OSD_LVL: R42.2, R43.1, R44.2, U18.1 (B2)
/OSD/OSD_SYNC: U2.1 (OUT), U10.27 (GPIO16)
/OSD/OSD_W: R42.1, U10.18 (GPIO14)
/OSD/VIDEO_IN: J32.1 (Pin_1_1), R41.1, R45.2, U18.3 (B1)
/OSD/VIDEO_OUT: J34.1 (Pin_1_1), R48.2
/OSD/VID_DC: C40.2, D9.1 (C), U2.4 (IN+)
/OSD/VID_FILT: C38.1, C40.1, R45.1
/PADS/BUZZER-: J21.1 (Pin_1_1), Q5.3 (D)
/PADS/CURRENT: J33.1 (Pin_1_1), P1.3, R9.1
/PADS/I2C0.SCL: J15.1 (Pin_1_1), R6.2, U10.8 (GPIO5)
/PADS/I2C0.SDA: J18.1 (Pin_1_1), R7.2, U10.7 (GPIO4)
/PADS/LED_STRIP: J10.1 (Pin_1_1), J24.1 (Pin_1_1), Q6.3 (D), R51.2
/PADS/M1: J35.1 (Pin_1_1), P1.5, U10.37 (GPIO25)
/PADS/M2: J37.1 (Pin_1_1), P1.6, U10.36 (GPIO24)
/PADS/M3: J39.1 (Pin_1_1), P1.7, U10.35 (GPIO23)
/PADS/M4: J41.1 (Pin_1_1), P1.8, U10.34 (GPIO22)
/PADS/PIOUART0_TX: J43.1 (Pin_1_1), U10.4 (GPIO2)
/PADS/PU0RX: J44.1 (Pin_1_1), P1.4, U10.5 (GPIO3)
/PADS/U1RX: J8.1 (Pin_1_1), U8.6, U10.10 (GPIO7)
/PADS/UART0_RX: J49.1 (Pin_1_1), U8.4, U10.3 (GPIO1)
/PADS/UART0_TX: J48.1 (Pin_1_1), U8.3, U10.2 (GPIO0)
/PADS/UART1_TX: J12.1 (Pin_1_1), U10.9 (GPIO6)
/POWER/1.8V_PG: D8.2 (A), R34.2, U12.3 (PG)
/POWER/10V_ENABLE: U3.5 (EN), U10.41 (GPIO27_ADC1)
/RP2350A/ADC_VBAT: C4.2, R1.1, R2.2, U10.43 (GPIO29_ADC3)
/RP2350A/BEEPER: Q5.1 (G), R23.2, U10.28 (GPIO17)
/RP2350A/D+: R37.2, USB1.A6 (DP1), USB1.B6 (DP2)
/RP2350A/D-: R24.1, USB1.A7 (DN1), USB1.B7 (DN2)
/RP2350A/ESC_CURR: C22.1, R9.2, U10.42 (GPIO28_ADC2)
/RP2350A/LED0: R52.1, U10.40 (GPIO26_ADC0)
/RP2350A/LED_STRIP_L: Q6.1 (G), U10.12 (GPIO8)
/RP2350A/XIN: C6.2, U10.21 (XIN), X1.1
/RP2350A/XOUT: R5.1, U10.22 (XOUT)
GND: C1.2, C3.2, C4.1, C5.2, C6.1, C7.2, C8.2, C9.2, C10.1, C11.2, C12.2, C13.2, C22.2, C24.2, C25.2, C28.2, C29.2, C31.2, C32.2, C33.2, C34.2, C35.2, C36.2, C37.2, C38.2, C39.2, C41.2, C42.2, C43.2, C44.2, C45.2, C46.2, Card1.6 (VSS), Card1.9, Card1.10, D2.1 (K), D4.1 (K), D5.1 (K), D7.1 (K), D8.1 (K), D9.2 (A), J14.1 (Pin_1_1), J20.1 (Pin_1_1), J26.1 (Pin_1_1), J27.1 (Pin_1_1), J31.1 (Pin_1_1), J42.1 (Pin_1_1), J46.1 (Pin_1_1), P1.2, P1.9, P1.10, Q5.2 (S), Q6.2 (S), R2.1, R3.1, R4.1, R23.1, R30.2, R32.2, R41.2, R44.1, R46.2, U1.2 (-VS), U2.3 (IN-), U2.5 (VEE), U3.1 (GND), U4.1 (GND), U7.3 (GND), U7.5 (PG), U7.7 (EP), U8.2, U8.5, U8.7, U8.8, U9.2 (SDx/AH1/Qvar1), U9.3 (SCx/AH2/Qvar2), U9.6 (GND), U9.7 (GND), U10.47 (VREG_PGND), U10.61 (EP), U11.1, U12.5 (GND), U12.7 (EP), U18.2 (GND), USB1.0 (EH), USB1.A1 (GND), USB1.A12 (GND), X1.2 (GND), X1.4 (GND)
unnamed: C10.2, R5.2, X1.3
unnamed: D2.2 (A), R53.2
unnamed: D4.2 (A), R33.2
unnamed: D5.2 (A), R50.2
unnamed: D7.2 (A), R36.2
unnamed: R38.1, U11.2
unnamed: R52.2, R53.1
unnamed: U1.3 (IN+), U18.4 (A)
unnamed: R46.1, R47.1, U1.4 (IN-)
unnamed: R47.2, R48.1, U1.1 (OUT)
unnamed: C26.2, U3.6 (CB)
unnamed: R29.1, R30.1, U3.4 (FB)
unnamed: C26.1, L2.1, U3.2 (SW)
unnamed: C27.2, U4.6 (CB)
unnamed: R31.1, R32.1, U4.4 (FB)
unnamed: C27.1, L3.1, U4.2 (SW)
unnamed: R38.2, U10.60 (QSPI_SS)
unnamed: R24.2, U10.51 (USB_DM)
unnamed: R37.1, U10.52 (USB_DP)
unnamed: C44.1, R15.2, U10.46 (VREG_AVDD)
unnamed: L4.2, U10.48 (VREG_LX)
unnamed: R3.2, USB1.A5 (CC1)
unnamed: R4.2, USB1.B5 (CC2)

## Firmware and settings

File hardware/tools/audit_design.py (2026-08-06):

#!/usr/bin/env python3
"""
OpenFC-Lite-Mini Design Audit.

Parses the KiCad 10 design using kicad-skip (schematics) and pcbnew (PCB netlist)
and produces a hardware inventory + Betaflight MFG validation report.

STALE: the refdes and GPIO map hardcoded below (U36 MCU, U14 IMU, U34/U35/U38 OSD,
GPIO0-47) are from the Rev 1 RP2354B/QFN-80 design. Rev 2 is RP2354A/QFN-60 with
U10 MCU, U9 IMU, U1/U2 OSD and GPIO0-29. Re-derive them against
hardware/docs/DESIGN.md before trusting the report. Output is not tracked in git.

Run with KiCad's bundled Python so pcbnew is available:
  /Applications/KiCad/KiCad.app/Contents/Frameworks/Python.framework/Versions/Current/bin/python3 \
    hardware/tools/audit_design.py
"""

from __future__ import annotations

import collections
import os
import re
import sys
from pathlib import Path

HW = Path(__file__).resolve().parents[1]
ROOT_SCH = HW / "OpenFC.kicad_sch"
PCB = HW / "OpenFC.kicad_pcb"
OUT = HW / "tools" / "design_audit.md"

# ---------- Parsers ----------

# kicad-skip: path setup for user-level install
sys.path.insert(0, os.path.expanduser("~/Library/Python/3.13/lib/python/site-packages"))
try:
    from skip import Schematic
except ImportError:
    print("ERROR: kicad-skip not available. pip install kicad-skip", file=sys.stderr)
    sys.exit(1)

try:
    import pcbnew  # type: ignore
except ImportError:
    print("ERROR: pcbnew not on path. Run with KiCad bundled Python.", file=sys.stderr)
    sys.exit(1)


# ---------- Schematic walk ----------

def list_sheets(root_sch: Path):
    """Return list of (sheetname, sheetfile) pairs referenced from root."""
    s = Schematic(str(root_sch))
    out = []
    for sh in s.sheet:
        props = {p.name: p.value for p in sh.property}
        out.append((props.get("Sheetname", "?"), props.get("Sheetfile", "?")))
    return out


def collect_symbols(sch_path: Path):
    """Parse a schematic; return list of dicts per placed symbol."""
    try:
        s = Schematic(str(sch_path))
    except Exception as e:
        print(f"  WARN: cannot parse {sch_path.name}: {e}", file=sys.stderr)
        return []
    out = []
    for sym in s.symbol:
        try:
            lib_id = sym.lib_id.value
        except Exception:
            continue
        props = {p.name: p.value for p in sym.property}
        ref = props.get("Reference", "?")
        if ref.startswith("#"):
            continue  # power flag / gnd
        # Filter out stray power-flag symbols mis-refed in sub-sheets (e.g. blackbox
        # sub-sheet has U1..U9 that are actually +3.3V / GND power symbols).
        lib_id_lower = lib_id.lower()
        if lib_id_lower.startswith("power:") or lib_id_lower == "power":
            continue
        out.append({
            "sheet": sch_path.stem,
            "ref": ref,
            "value": props.get("Value", ""),
            "footprint": props.get("Footprint", ""),
            "mpn": props.get("MPN", ""),
            "lcsc": props.get("LCSC_Part", "") or props.get("LCSC", ""),
            "mfr": props.get("Manufacturer", ""),
            "description": props.get("Description", ""),
            "lib_id": lib_id,
            "dnp": bool(getattr(sym, "dnp", None) and sym.dnp.value),
            "on_board": bool(getattr(sym, "on_board", None) and sym.on_board.value),
        })
    return out


# ---------- PCB walk ----------

def load_pcb(pcb_path: Path):
    return pcbnew.LoadBoard(str(pcb_path))


def footprint_index(board):
    """ref -> {pads: {pad_num: netname}, funcs: {pad_num: pinfunc}, ...}"""
    idx = {}
    for fp in board.GetFootprints():
        r = fp.GetReference()
        pads = {}
        funcs = {}
        for pad in fp.Pads():
            num = pad.GetNumber()
            pads[num] = pad.GetNetname() or ""
            try:
                funcs[num] = pad.GetPinFunction() or ""
            except Exception:
                funcs[num] = ""
        idx[r] = {
            "value": fp.GetValue(),
            "footprint": fp.GetFPID().GetLibItemName().c_str() if hasattr(fp.GetFPID(), "GetLibItemName") else "",
            "pads": pads,
            "funcs": funcs,
        }
    return idx


def net_to_refpins(board):
    """netname -> list of (ref, pad_num, pad_name/function)"""
    d = collections.defaultdict(list)
    for fp in board.GetFootprints():
        r = fp.GetReference()
        for pad in fp.Pads():
            name = pad.GetNetname() or ""
            d[name].append((r, pad.GetNumber(), pad.GetPinFunction() if hasattr(pad, "GetPinFunction") else ""))
    return d


# ---------- Classification ----------

FUNC_RULES = [
    ("MCU",       lambda s: s["ref"].startswith("U") and "RP235" in s["value"].upper()),
    ("IMU",       lambda s: "LSM6" in s["value"].upper() or "ICM-4" in s["value"].upper() or "MPU6" in s["value"].upper()),
    ("Buck",      lambda s: s["ref"].startswith("U") and "LMR5" in s["value"].upper()),
    ("LDO",       lambda s: s["ref"].startswith("U") and ("LP5912" in s["value"].upper() or "NCV8187" in s["value"].upper())),
    ("Power Mux", lambda s: "TPS2116" in s["value"].upper()),
    ("OSD",       lambda s: "TLV3201" in s["value"].upper() or "TLV9061" in s["value"].upper() or "LVC1G3157" in s["value"].upper() or "PI3A223" in s["value"].upper()),
    ("SD card",   lambda s: "TF-" in s["value"].upper() or "SD" == s["ref"][:2].upper() and "CARD" in s["description"].upper()),
    ("USB",       lambda s: s["ref"].startswith("USB") or "USB" in s["value"].upper() and s["ref"].startswith("J") or s["ref"] == "USB1"),
    ("Switch",    lambda s: s["ref"].startswith("SW") or "TS2306" in s["value"].upper()),
    ("Connector", lambda s: s["ref"].startswith("J") or "CONN" in s["lib_id"].upper()),
    ("Test Pad",  lambda s: s["ref"].startswith("TP")),
    ("MOSFET",    lambda s: s["ref"].startswith("Q")),
    ("Diode/LED", lambda s: s["ref"].startswith("D") and ("LED" in s["value"].upper() or "LED" in s["description"].upper())),
    ("Diode",     lambda s: s["ref"].startswith("D")),
    ("Inductor",  lambda s: s["ref"].startswith("L")),
    ("Ferrite",   lambda s: s["ref"].startswith("FB")),
    ("Resistor",  lambda s: s["ref"].startswith("R")),
    ("Capacitor", lambda s: s["ref"].startswith("C")),
    ("IC",        lambda s: s["ref"].startswith("U")),
]

def classify(sym):
    for name, fn in FUNC_RULES:
        try:
            if fn(sym):
                return name
        except Exception:
            continue
    return "Misc"


# ---------- Report builders ----------

def refs_on_net(net2rp, netname, exclude_refs=None):
    exclude_refs = set(exclude_refs or [])
    return [(r, n, f) for (r, n, f) in net2rp.get(netname, []) if r not in exclude_refs]


def find_caps_between(syms_by_ref, net2rp, netname_a, netname_b="GND"):
    """Return list of cap refs having one pad on netname_a and other on netname_b."""
    caps_on_a = {r for (r, _, _) in net2rp.get(netname_a, []) if r.startswith("C")}
    caps_on_b = {r for (r, _, _) in net2rp.get(netname_b, []) if r.startswith("C")}
    return sorted(caps_on_a & caps_on_b, key=lambda x: int(re.sub(r"\D", "", x) or 0))


def find_nets_matching(net2rp, *patterns):
    pats = [re.compile(p, re.I) for p in patterns]
    return [n for n in net2rp if any(p.search(n) for p in pats)]


def pad_net(fp_idx, ref, pad_num):
    return fp_idx.get(ref, {}).get("pads", {}).get(str(pad_num), "")


def md_table(headers, rows):
    out = ["| " + " | ".join(headers) + " |",
           "|" + "|".join(["---"] * len(headers)) + "|"]
    for row in rows:
        out.append("| " + " | ".join(str(x) for x in row) + " |")
    return "\n".join(out)


# ---------- Main audit ----------

def main():
    lines = []
    W = lines.append

    W("# OpenFC-Lite Design Audit\n")
    W(f"Generated from `{ROOT_SCH.name}` + `{PCB.name}` via kicad-skip + pcbnew.\n")

    # ---- 1. Hierarchy ----
    W("## 1. Top-level Hierarchy\n")
    sheets = list_sheets(ROOT_SCH)
    rows = []
    for name, path in sheets:
        exists = (HW / path).exists()
        rows.append([name, f"`{path}`", "yes" if exists else "**MISSING**"])
    W(md_table(["Sheetname", "File", "On disk"], rows))
    W("")
    W(f"Root schematic: `{ROOT_SCH.name}`, {len(sheets)} sub-sheet(s) referenced.\n")

    # ---- 2. Components ----
    W("## 2. Component Inventory\n")
    all_syms = []
    for name, path in sheets:
        p = HW / path
        if p.exists():
            all_syms.extend(collect_symbols(p))
    # Deduplicate by ref (symbols may appear in multiple places due to power/gnd)
    seen = {}
    for s in all_syms:
        seen.setdefault(s["ref"], s)
    syms = list(seen.values())

    W(f"Total placed refs: **{len(syms)}** (DNP excluded: "
      f"{len([s for s in syms if s['dnp']])}).\n")

    by_func = collections.defaultdict(list)
    for s in syms:
        by_func[classify(s)].append(s)

    # Print ICs, regulators, connectors etc fully; print caps/resistors summarized
    DETAIL_FUNCS = ["MCU", "IMU", "Buck", "LDO", "Power Mux", "OSD",
                    "SD card", "USB", "Switch", "MOSFET",
                    "Diode/LED", "Diode", "IC", "Inductor", "Ferrite"]
    def ref_sort_key(ref):
        m = re.match(r"([A-Za-z]+)(\d+)", ref)
        if m:
            return (m.group(1), int(m.group(2)))
        return (ref, 0)

    for fn in DETAIL_FUNCS:
        items = sorted(by_func.get(fn, []), key=lambda x: ref_sort_key(x["ref"]))
        if not items:
            continue
        W(f"### {fn} ({len(items)})\n")
        rows = []
        for s in items:
            mpn = s["mpn"] or s["value"]
            dnp = " DNP" if s["dnp"] else ""
            rows.append([s["ref"] + dnp, s["value"], mpn, s["lcsc"] or "-",
                         s["mfr"] or "-", s["footprint"].split(":")[-1] if s["footprint"] else "-",
                         s["sheet"]])
        W(md_table(["Ref", "Value", "MPN", "LCSC", "Mfr", "Footprint", "Sheet"], rows))
        W("")
    # Connector summary only (detail in section 14)
    conns = by_func.get("Connector", [])
    if conns:
        W(f"### Connector / Solder Pads ({len(conns)})\n")
        W("(full net list in section 14)\n")
        # group by footprint
        fp_count = collections.Counter((s["footprint"].split(":")[-1] or "-", s["sheet"]) for s in conns)
        rows = [[fp, sh, c] for (fp, sh), c in sorted(fp_count.items())]
        W(md_table(["Footprint", "Sheet", "Count"], rows))
        W("")

    # Passives summary
    W("### Passives summary\n")
    rows = []
    for fn in ("Resistor", "Capacitor", "Test Pad"):
        items = [s for s in by_func.get(fn, []) if not s["dnp"]]
        dnp = [s for s in by_func.get(fn, []) if s["dnp"]]
        rows.append([fn, len(items), len(dnp)])
    W(md_table(["Function", "Placed", "DNP"], rows))
    W("")

    # ---- Load PCB for net-level analysis ----
    board = load_pcb(PCB)
    fp_idx = footprint_index(board)
    net2rp = net_to_refpins(board)

    # ---- 3. Power tree ----
    W("## 3. Power Tree\n")
    W("```")
    W("+BATT -> U6 (LMR51420YFDDCR buck) -> +12V   [switchable via GPIO11 via Q?]")
    W("+BATT -> U7 (LMR51420YFDDCR buck) -> +5V_BUCK")
    W("+5V_BUCK -+")
    W("          +- U33 (TPS2116 mux) -> +5V")
    W("VBUS(USB)-+")
    W("+5V -> U13 (LP5912-3.3) -> +3.3V")
    W("+3.3V -> U36 (RP2354B VREG) -> +1.1V_CORE (DVDD)")
    W("+5V -> U21 (NCV8187 LDO) -> +1.8V_GYRO")
    W("```\n")

    regs = [
        ("U6",  "LMR51420YFDDCR", "12V buck"),
        ("U7",  "LMR51420YFDDCR", "5V buck"),
        ("U13", "LP5912-3.3DRVR", "3.3V LDO"),
        ("U21", "NCV8187AMT180TAG", "1.8V gyro LDO"),
        ("U33", "TPS2116DRLR", "5V power mux"),
    ]
    rows = []
    for ref, mpn, role in regs:
        fp = fp_idx.get(ref, {})
        pads = fp.get("pads", {})
        # summarise input / EN / output if we can infer by pin function from schematic
        # Just print key pads
        rows.append([ref, role, mpn, fp.get("footprint", "-"),
                     "; ".join(f"{k}→{v}" for k, v in sorted(pads.items(), key=lambda x: int(x[0]) if x[0].isdigit() else 99))])
    W(md_table(["Ref", "Role", "MPN", "Footprint", "Pad → Net"], rows))
    W("")

    # ---- 4. Bypass caps per rail ----
    W("## 4. Bypass caps per power rail\n")
    rails = ["+BATT", "+12V", "+5V_BUCK", "+5V", "VBUS", "+3.3V", "+1.8V_GYRO",
             "+1.1V", "+1.1V_CORE", "DVDD"]
    rows = []
    for rail in rails:
        # try exact, then with leading /
        candidates = [rail, "/" + rail, rail.lstrip("+"), "/" + rail.lstrip("+")]
        found_net = None
        for c in candidates:
            if c in net2rp:
                found_net = c
                break
        if not found_net:
            # try loose match
            loose = [n for n in net2rp if n.strip("/+").upper() == rail.strip("/+").upper()]
            if loose:
                found_net = loose[0]
        if not found_net:
            rows.append([rail, "- (net not found)", "-", "-"])
            continue
        caps = find_caps_between({}, net2rp, found_net, "GND")
        # count how many pins are on this net (fanout size)
        fanout = len(net2rp.get(found_net, []))
        rows.append([rail, found_net, len(caps), ", ".join(caps) if caps else "-"])
    W(md_table(["Rail", "Net", "# Caps to GND", "Cap refs"], rows))
    W("")
    # Also report ALL nets that look like rails
    rail_like = [n for n in net2rp if re.search(r"(^|/)(\+?\d+V|VBUS|VBAT|VDD|AVDD|DVDD|VREG)", n, re.I)]
    W("Rail-like nets present:\n")
    W(", ".join(f"`{n}`" for n in sorted(set(rail_like))))
    W("")

    # ---- 5. ADC inputs ----
    W("## 5. ADC Inputs\n")
    adc_nets = {
        "VBAT_SENSE": ["VBAT", "VBATT_SENSE", "VBAT_ADC", "BATT_ADC", "VBAT_SCALE", "BATTERY_ADC"],
        "CURR_SENSE": ["CURRENT", "I_SENSE", "CURR_ADC", "CURR_SENSE", "IMON", "CURRENT_ADC"],
        "RSSI":       ["RSSI", "RSSI_ADC"],
        "EXT":        ["EXT_ADC", "ADC_EXT", "EXT"],
    }
    # Try to find the MCU's actual ADC pins: GPIO40,41,45,47 per CLAUDE.md
    mcu_ref = "U36"
    mcu_fp = fp_idx.get(mcu_ref, {})
    # The ADC nets go to MCU pins: find them by following net back to U36
    rows = []
    for role, candidates in adc_nets.items():
        net = None
        for c in candidates:
            match = [n for n in net2rp if c.upper() in n.upper()]
            if match:
                net = sorted(match, key=len)[0]
                break
        if not net:
            rows.append([role, "- not found", "-", "-", "-"])
            continue
        # Find MCU pad carrying this net
        mcu_pad = "-"
        for p, n in mcu_fp.get("pads", {}).items():
            if n == net:
                mcu_pad = p
                break
        # Find resistors on the net
        res = [r for (r, _, _) in net2rp.get(net, []) if r.startswith("R")]
        caps = find_caps_between({}, net2rp, net, "GND")
        rows.append([role, net, mcu_pad,
                     ", ".join(sorted(set(res))) or "-",
                     ", ".join(caps) or "**NONE**"])
    W(md_table(["Role", "Net", "MCU pad", "Resistors on net", "Bypass caps to GND"], rows))
    W("")
    W("**Check**: A CURRENT-sense ADC input WITHOUT a bypass cap at the MCU pin is a "
      "Betaflight MFG-guideline violation (noise couples straight into ADC).\n")

    # ---- 6. SPI buses & CS pull-ups ----
    W("## 6. SPI Buses & CS pull-ups\n")
    spi_nets = {
        "SPI0 SCK":  [n for n in net2rp if re.search(r"SPI0?_?SCK|GYRO_?SCK|IMU_?SCK", n, re.I)],
        "SPI0 MOSI": [n for n in net2rp if re.search(r"SPI0?_?(MOSI|SDI|SDA)|GYRO_?MOSI|IMU_?MOSI", n, re.I)],
        "SPI0 MISO": [n for n in net2rp if re.search(r"SPI0?_?(MISO|SDO)|GYRO_?MISO|IMU_?MISO", n, re.I)],
        "IMU CS":    [n for n in net2rp if re.search(r"(IMU|GYRO).*CS|CS_?(IMU|GYRO)", n, re.I)],
        "SD CS":     [n for n in net2rp if re.search(r"SD.*CS|CS_?SD|BB_?CS", n, re.I)],
        "SD MOSI":   [n for n in net2rp if re.search(r"SD.*MOSI|SD.*DI|SD_?CMD", n, re.I)],
        "SD MISO":   [n for n in net2rp if re.search(r"SD.*MISO|SD.*DO|SD_?DAT0?", n, re.I)],
        "SD SCK":    [n for n in net2rp if re.search(r"SD.*SCK|SD.*CLK", n, re.I)],
    }
    rows = []
    for role, nets in spi_nets.items():
        if not nets:
            rows.append([role, "-", "-", "-"])
            continue
        net = nets[0]
        # list refs on that net
        refs = sorted(set(r for (r, _, _) in net2rp[net]))
        # resistors on net (pull-up candidates)
        rs = [r for r in refs if r.startswith("R")]
        rows.append([role, net, ", ".join(refs), ", ".join(rs) or "-"])
    W(md_table(["Signal", "Net", "Refs on net", "Resistors (pull-ups?)"], rows))
    W("")

    # Specific checks for CS pull-ups
    W("### CS pull-up check (to +3.3V)\n")
    cs_checks = []

    def find_cs_pad(ref):
        """Return (pad_num, netname) for the CS pin of a footprint, using pin function."""
        fp = fp_idx.get(ref, {})
        for p, func in fp.get("funcs", {}).items():
            if re.search(r"(^|_)CS(_|$)", func or "", re.I):
                return p, fp.get("pads", {}).get(p, "")
        return None, None

    # IMU CS -> U14 using pin function
    pad, net = find_cs_pad("U14")
    cs_checks.append((f"IMU_CS (U14 pad {pad})", net))
    # SD CS -> Card2 pad 2 (TF-021B-H265 pinout: pin2=CS/DAT3)
    for ref, fp in fp_idx.items():
        v = fp.get("value", "").upper()
        if "TF-" in v or "MICROSD" in v:
            # TF socket pad 2 = CS in SPI mode
            n = fp.get("pads", {}).get("2", "")
            cs_checks.append((f"SD_CS ({ref} pad 2)", n))
            break
    rows = []
    for role, net in cs_checks:
        if not net:
            rows.append([role, "-", "-", "-"])
            continue
        rs = [r for (r, _, _) in net2rp.get(net, []) if r.startswith("R")]
        # Does any of those R's touch +3.3V or +3V3?
        has_pullup = False
        pu_ref = "-"
        for rref in rs:
            rpads = fp_idx.get(rref, {}).get("pads", {})
            other_nets = set(rpads.values()) - {net}
            if any(re.search(r"3V3|3\.3V|VDDIO", x, re.I) for x in other_nets):
                has_pullup = True
                pu_ref = rref
                break
        rows.append([role, net, "YES" if has_pullup else "NO", pu_ref])
    W(md_table(["CS line", "Net", "Pull-up present?", "Pull-up ref"], rows))
    W("")

    # ---- 7. Status LEDs ----
    W("## 7. Status LEDs (non-WS2812)\n")
    leds = [s for s in syms if s["ref"].startswith("D") and
            ("LED" in s["value"].upper() or "LED" in (s["description"] or "").upper())]
    rows = []
    for led in sorted(leds, key=lambda x: x["ref"]):
        ref = led["ref"]
        fp = fp_idx.get(ref, {})
        pads = fp.get("pads", {})
        # LEDs usually have A/K or 1/2
        pin_nets = ", ".join(f"{k}→{v}" for k, v in pads.items())
        # Try to identify MCU pin driving it (non-rail end)
        drivers = [v for v in pads.values() if not re.search(r"\+?(\d+V|GND|VBUS|VBAT)", v, re.I)]
        rows.append([ref, led["value"], led["mpn"] or "-", pin_nets, ", ".join(drivers) or "-"])
    W(md_table(["Ref", "Value/Color", "MPN", "Pad nets", "Likely MCU-side net"], rows))
    W("")
    # Blue LED check
    blue = [l for l in leds if "BLUE" in l["value"].upper() or "BLU" in l["value"].upper()]
    W(f"Blue LED (Betaflight LED0 requirement): **{'PRESENT' if blue else 'MISSING'}** "
      f"({', '.join(l['ref'] for l in blue) or 'none'})\n")

    # ---- 8. I2C ----
    W("## 8. I2C Pull-ups\n")
    sda_net = [n for n in net2rp if re.search(r"I2C.*SDA|SDA$|/SDA", n, re.I)]
    scl_net = [n for n in net2rp if re.search(r"I2C.*SCL|SCL$|/SCL", n, re.I)]
    rows = []
    for role, nets in (("I2C_SDA", sda_net), ("I2C_SCL", scl_net)):
        if not nets:
            rows.append([role, "-", "-", "-"])
            continue
        net = nets[0]
        refs = sorted(set(r for (r, _, _) in net2rp[net]))
        rs = [r for r in refs if r.startswith("R")]
        has_pullup = False
        for rref in rs:
            rpads = fp_idx.get(rref, {}).get("pads", {})
            if any(re.search(r"3V3|3\.3V|VDDIO", x, re.I) for x in rpads.values()):
                has_pullup = True
                break
        rows.append([role, net, ", ".join(refs), "YES" if has_pullup else "**NO**"])
    W(md_table(["Signal", "Net", "Refs on net", "Pull-up to 3.3V"], rows))
    W("")

    # ---- 9. MCU pinout ----
    W("## 9. RP2354B (U36) Pinout\n")
    mcu_fp = fp_idx.get("U36", {})
    pads = mcu_fp.get("pads", {})
    rows = []
    for p in sorted(pads.keys(), key=lambda x: int(x) if x.isdigit() else 999):
        n = pads[p]
        # skip internal / power pads for clarity (keep but mark)
        rows.append([p, n])
    W(md_table(["Pad", "Net"], rows))
    W("")

    # ---- 10. OSD circuit ----
    W("## 10. OSD Circuit\n")
    osd_refs = [s["ref"] for s in syms if s["ref"] in ("U34", "U35", "U38")]
    rows = []
    for ref in osd_refs:
        fp = fp_idx.get(ref, {})
        rows.append([ref, fp.get("value"), fp.get("footprint"),
                     "; ".join(f"{k}→{v}" for k, v in fp.get("pads", {}).items())])
    W(md_table(["Ref", "Value", "Footprint", "Pad → Net"], rows))
    W("")
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

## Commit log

2026-06-05 Rev 2 (RP2354A): finalize design, update docs, clean repo (#5)
    * docs(readme): add analog OSD BOM to Rev 2 change list
    Document OSD debugging findings and component changes as a new
    Analog OSD section in the Rev 2 Change List:
    - HW-12: U19 op-amp TLV9061IDPWR -> COS8051SOT (175MHz video-grade RRIO)
    - HW-13: output front-end add AC-couple + DC-restore, power U19 from +5V
    - HW-14: U20 comparator TLV3201AIDBVR -> TLV7031DPWR (push-pull, X2SON, ~75% smaller)
    - HW-15: add OSD_EN select pull-down (datasheet-required, defaults to pass-through)
    - U18 / D9 verified correct, no change; OSD GPIO mapping noted (PA4/5/6)
    Also fix HW-11 beeper GPIO: GPIO6 -> GPIO7 (GPIO6 is OSD_SYNC per netlist).
    Co-Au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
    [OpenFC.kicad_pcb, OpenFC.kicad_sch, blackbox.kicad_sch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]
2026-06-06 Rev 2: update PCB layout and project settings
    [OpenFC.kicad_pcb]
2026-06-06 docs: clarify IMU part; add DESIGN_NOTES; ignore board STEP exports
    - README: IMU populated as LSM6DSV16XTR (production part not yet locked)
    - add hardware/DESIGN_NOTES.md: design rationale ported from OpenFC-Lite (RP2354B)
    - gitignore: ignore board-level *.step exports (e.g. Lite-Mini.step, 21MB)
2026-06-06 docs(schematic): add design annotations to all sheets
    Port on-canvas engineering comments from OpenFC-Lite (RP2354B), adapted to the
    Mini layout. +41 text items across root, rp2350a, power, imu, osd, blackbox,
    pads. Annotation/text only — no net or connectivity changes. Mirrors
    hardware/DESIGN_NOTES.md.
    [OpenFC.kicad_sch, blackbox.kicad_sch, imu.kicad_sch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]
2026-06-06 feat(doc): add DOC_ project text variables
    Project-level documentation SSoT in .kicad_pro: DOC_NAME/HANDLE/VARIANT/TAGLINE/FIRMWARE/PROTOCOL/MCU/INPUT/RATING.
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2026-06-06 docs: gyro LDO is NCV8187 1.2A high-PSRR (fix vs design + datasheet)
    Was mislabelled 300mA; the 1.2A rating clears BF §3.1.2's ≥500mA. Reconciled against the on-canvas KiCad comment.
2026-06-06 chore(bom): consolidate LCSC Part -> LCSC field across schematic, library, footprints, project
    Single canonical LCSC field (was split LCSC / LCSC Part). Every part resolves to one LCSC code; netlist verified, no duplicates. Includes Rev2 re-annotation resync re-save.
    [OpenFC.kicad_pcb, blackbox.kicad_sch, imu.kicad_sch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]
2026-06-06 fix(power): break accidental +3.3V↔GND short in power sheet
    A +3.3V power symbol (#PWR084) and a GND symbol (#PWR068) were tied to the same
    net during schematic annotation, merging the entire ground into +3.3V (no GND
    net, 14 shorted caps, LDO IN/GND/OUT shorted). Separated them; ERC +3.3V/GND
    conflict cleared, GND net restored (91 pins), 0 shorted caps. PCB unaffected.
    [power.kicad_sch]
2026-06-06 docs: Rev 2 board renders (standardized top/bottom)
    kicad-cli 3D renders, 1600x1600 high-quality, transparent bg, ortho top/bottom. Replaces Rev 1 images.
2026-06-06 docs: fix sibling framing — both Mini and full-size Lite ship for Rev 2
    Mini and full-size OpenFC-Lite are parallel Rev 2 boards (not 'Lite derived later'); full-size adds OSD debug pads.
2026-06-07 docs: via-free board renders
    Re-render top/bottom board images with vias removed for a cleaner look.
    KiCad cannot render tented vias, so vias were temporarily stripped via the
    pcbnew API for rendering only; source .kicad_pcb files are unchanged.
2026-06-07 docs: re-render boards without floor shadows
    Re-render top/bottom images at basic quality so the soldermask floor
    shadow halo is gone. Vias still stripped for the render only (via pcbnew),
    source .kicad_pcb files unchanged.
2026-06-07 docs: render boards without solder paste
    Strip the solder-paste layer (and vias) for the render only so SMD pads
    show as clean copper instead of gray paste deposits. Source .kicad_pcb
    files unchanged.
2026-06-07 docs: remove DESIGN_NOTES, trim README boilerplate
    - Delete DESIGN_NOTES.md (and its gitignore exception)
    - Drop the Manufacturing / production-export section
    - Remove the canonical-reference boilerplate blurb
    - ESC boards: AM32 bootloader ships pre-loaded, firmware flashed via am32.ca
2026-06-20 fix(3d): attach X2SON-4 model to placed U2 (TLV7031DPWR)
    The lib.pretty footprint and lib.3dshapes/X2SON-4_...-DPW.step/.wrl
    already existed; only the placed U2 instance had lost its model block,
    so it rendered as a bare pad in the teardown faces. Re-attached the
    model from the library via pcbnew API (no S-expr edit). Zone fills were
    recomputed by the pcbnew save (cosmetic, no net/geometry change).
    [OpenFC.kicad_pcb]
2026-08-04 chore: wire shared Incutec KiCad library
    Adds incutec-hw/KiCad-Library as submodule at libs/KiCad-Library, pinned
    to the feat/complete-library build. Project lib tables gain the Incutec
    sym+fp entries via ${KIPRJMOD} relative paths. Existing local libraries
    untouched (frozen, see the library repo MANIFEST).
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2026-08-05 Scrub internal working notes from public docs
    - imu-selection/README.md: remove owner line, per-person conversation log,
    personal repo pointers, and resolved bug diary; keep the technical IMU
    comparison, flight-data findings, and root-cause analysis rewritten
    impersonally
    - rp2354a-routing-validation.md: impersonal fix/change-list wording, drop
    references to untracked context files
    - README.md: move the three OPEN change-log items into
    hardware/research/open-items.md (new file)
    - design_audit.md: reference the documented pin plan instead of an
    untracked context file
2026-08-05 hardware: add LP5912-1.8 lib parts and layout working state
    - LP5912-1.8DRVR symbol in project lib, WSON-6 2x2mm footprint with
    thermal vias, matching STEP model (mirrors OpenFC-Lite)
    - OpenFC.kicad_pcb layout working state
    [OpenFC.kicad_pcb]
2026-08-05 Adopt OpenDrone repo standard
    Restructure README to the OpenESC-30x30 standard: overview, status,
    certification, links, compact specs, layout, entry points, build,
    manufacturing, license. Relocate GPIO map, PIO allocation, IMU notes,
    power tree, OSD detail, and firmware target to hardware/docs/DESIGN.md;
    revision history and the Rev 2 change list to CHANGELOG.md. Add
    CONTRIBUTING.md and AGENTS.md.
    Fact fixes: FB_OSD driver merged upstream (BF#14882, 2026-04-22),
    USB series resistors are R15/R24/R37 after Rev 2 re-annotation,
    sibling OpenFC-Lite has no full-size SD, KiCad 10 not 9, U3/U4 BOM
    fields already carry the LMR51430 MPN and C5219261, Betaflight target
    noted as not yet published, ord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
2026-08-05 Restore lost change-log detail from old README
    Re-add the U19/U20 pre-rework OSD designators, the BF section 3.1.2
    500 mA citation for the U6 gyro LDO, and state the ~22 px comparator
    offset as a PIO timing requirement rather than an unverified done-claim.
2026-08-06 Fix verification findings: replace em and en dashes in docs and scripts
    [audit_design.py]
2026-08-06 Rewrite CONTRIBUTING for humans: file locking, render proof, sign-off
    KiCad files cannot be merged, so the doc now leads with claiming files via
    git lfs lock and issue-first discussion, the convention used by LumenPnP and
    Ultimate Hacking Keyboard. Adds .gitattributes marking design files lockable.
    Drops the internal documentation-style rule that meant nothing to contributors.
2026-08-06 Fix contradictions and duplicated information
    Contradictions, all resolved against the design files (U10 pad nets and
    component values parsed from hardware/OpenFC.kicad_pcb):
    - LED series resistors in DESIGN.md re-derived from the board: D2 is
    R52+R53 = 150R from GPIO26 (not 510R), D7 is R36 = 510R from +3.3V
    (not 680R), and the missing D8 row is added. Currents recomputed.
    - OSD op-amp supply corrected from +5 V to +3.3 V (U1 pin 5 is on the
    +3.3V net); the headroom question is raised as an open item.
    - EMC checklist rewritten for the RP2354A: SPI0/SPI1 swapped to match
    the netlist (IMU on SPI1, SD on SPI0), USB series R corrected to 30R
    at pads 51/52, core inductor L1 to L4, RSS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
    [add_emc_note.py, audit_design.py]
2026-08-06 Local libraries are the working default again
    New parts go into this repo's local libraries. KiCad-Library becomes a mirror
    of parts we already use or stock, worth checking first because a hit means we
    have sourced it before. Promotion into it is a separate step.
2026-08-06 Swap 1.8V LDO and IMU, fix BOM/CPL export hygiene
    Part changes, both schematic and PCB:
    - U6 NCV8187AMT180TAG (stock 0 at JLC) replaced by U12 LP5912-1.8DRVR
    (C2876234). Same WSON-6 2x2 land pattern as the LP5912-3.3 at U7, so no
    layout change. PG is retained. PSRR at the 1 mA gyro load is ~85 dB to
    1 kHz and ~70 dB at 10 kHz per datasheet Figure 23.
    - PG indicator rewired: pull-up from +5V to PG, LED from PG to GND, so the
    LED lights when the rail is good instead of when it has failed.
    - U9 LSM6DSV16XTR replaced by BMI270 (C2836813). Bosch Table 22 matches the
    existing LGA-14 symbol pin for pin, so no rewire and no CPL rotation change.
    - C33, C34 22uF 0402 moved from C105226 to C4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
    [OpenFC.kicad_pcb, imu.kicad_sch, pads.kicad_sch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]
2026-08-08 Fix SOD-882 3D offset in lib, re-render board images
    Same EasyEDA absolute-coordinate 3D offset bug as OpenFC-Lite: the
    SOD-882 (RB161QS-40 RPP diodes D3/D10) library footprint placed the
    model (-911.61, 887.73) mm off the board. Fixed to zero offset via the
    pcbnew API. Board-instance fixes (D3/D10 offsets plus Q5 losing a
    0.5 mm 3D float that its twin Q6 never had) are in the working tree
    with the in-progress layout changes; renders taken from that state and
    verified: all ICs present, both diodes seated.
2026-08-11 docs: BMI270 and LP5912 as built, Discord-first contributing
    The 1.8 V gyro LDO is LP5912-1.8DRVR (U12), not the NCV8187, and its spec line
    now carries the LP5912's real numbers: 500 mA, 75 dB PSRR at 1 kHz, 12 uVRMS.
    Production IMU is BMI270. Rev2 revision history left untouched.
    CONTRIBUTING.md now asks contributors to raise proposals in Discord and tag the
    developers before opening an issue.
2026-08-11 Rev 3: LP5912 gyro LDO, BMI270
    Gyro supply moves to LP5912-1.8DRVR (U12, C2876234); the NCV8187AMT180TAG is
    gone from schematic and board. IMU is BMI270 (U9). Bucks stay LMR51430YFDDCR,
    which has adequate margin for the 6S ceiling this board shares with the 20x20
    ESC.
    ERC and DRC reviewed by the maintainer.
    [OpenFC.kicad_pcb, power.kicad_sch]
2026-08-13 Add prebuilt Betaflight uf2 (#21)
    Target OPENFC_LITE_MINI_RP2350A, 2026.6.0-alpha, built from
    Just4Stan/betaflight branch pico-enable-osd-hd. IO follows the
    silkscreen; no pin workaround, unlike the full-size Lite Rev 2.
    The binary is a Betaflight build and stays under GPL-3.0.
2026-08-13 Standardise: AGENTS.md, trimmed README, canonical dotfiles, design rules (#22)
    Adopts the org-wide shape, matching the ESC and RX repos. Four root files,
    CONTRIBUTING is a stub pointing at OpenDrone-hw/.github.
    AGENTS.md replaces hardware/docs/DESIGN.md and the gitignored CLAUDE.md, and
    absorbs the EMC checklist and layout notes that were sitting in hardware/tools/.
    It states in the Repo table that this project is called OpenFC in both FC repos,
    which is the ambiguity that has already caused a part to be imported into the
    wrong one.
    hardware/OpenFC.kicad_dru now carries the canonical block. On OpenFC-Lite the
    file existed on disk but was gitignored and untracked, so the design intent had
    n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
2026-08-13 README: standardised link row, specs from the shop, status badge (#23)
    Same shape in every board repo.
    Outbound links move out of prose into one badge row: status, shop, the product's
    Discord channel, its build video, and OSHWA where the board is certified. The
    status badge links to the stage ladder in the org CONTRIBUTING rather than
    describing the stage here.
    The specification table is synced from the product page on opendrone.be, which
    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
2026-08-14 Drop helpers that live in OpenDrone-Scripts
    The openfc_* extract/report trio and set_edgecuts_width.py have their
    canonical copies in software/OpenDrone-Scripts/kicad. add_mpn_fields.py
    stays: it hardcodes this repo's root-sheet list. audit_design.py stays:
    the two OpenFC copies have drifted and are board-specific.
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2026-08-14 Normalise board setup to the line standard
    The canonical dru's copper-to-copper rule demanded 0.1 mm outer
    clearance against the 0.09 line standard stated in the same file,
    flooding DRC with false errors on standard-routed boards. Removed;
    the project-file floors gate this already. Rule floors set to the
    line standard where the routed board complies, verified by DRC:
    zero new violations.
2026-08-14 Drop the KiCad-Library submodule: nothing references it
    No symbol, footprint or 3D model in the design resolves through
    libs/KiCad-Library; every part is in the repo's local libraries. The
    submodule only cost --recursive clones and pin maintenance. Lib-table
    rows for the dead Incutec nickname removed so KiCad stops warning.
2026-08-14 4V5 rework: TPS2116 mux replaced by DSK24 diode-OR
    U5, its diodes, R27/R28 and C30 removed. D6 from the buck output and
    D10 from +5V_USB feed the new +4v5 net for the LDOs, JST and pads; the
    buck output is plain +5V to the external pads. DSK24 footprint and 3D
    model committed with the change. Shop badge gold.
    [OpenFC.kicad_pcb, pads.kicad_sch, power.kicad_sch]
2026-08-14 Rebuild E6 substitute STEP models from the trusted wrl geometry
    The .step files beside these .wrl models were different parts (USB-C
    3.5x oversized, etc), and the upstream LCSC .step is the same wrong
    file, so kicad-cli --subst-models shipped wrong geometry in every STEP
    export while the 3D viewer looked perfect. Rebuilt as tessellated STEP
    solids from the .wrl the viewer renders, via
    OpenDrone-Scripts/kicad/wrl_to_step.py: bbox and origin now match to
    0.000 mm. check_models reports zero E6, export unblocked.
    [OpenFC.kicad_pcb]
2026-08-14 Rev 3.1 release prep: renders, 4V5 power tree, revisions
    The committed board now matches the verified fab export exactly
    (check_export.py C1-C3 clean). Renders regenerated from it.
2026-08-15 docs: standardise AGENTS.md, netlist-verified
    AGENTS.md rebuilt on the org template and netlist-verified: SPI bus assignment corrected, phantom connectors removed, 3 UARTs, BMI270, USB-only flashing documented. Maintainer added to README. DOC text variables cleaned.
2026-08-15 docs: add voltage range to input spec
    Input row now reads 3-6S LiPo (9.0-25.2 V).
2026-08-17 switch to 0.1mm trace width and spacing for more options in PCB printing
    [OpenFC.kicad_pcb]
2026-08-17 check in missing changes that will resolve more of the checks
    [OpenFC.kicad_pcb]
2026-08-18 rev3.2: zone refill, silkscreen rev, stale DRC exclusions removed
    No routing change: 1063 tracks and vias before and after, none added,
    none removed. The board delta is the zone refill KiCad wrote when the
    0.1 mm line landed, plus REV3.2 on the silkscreen.
    Project file drops the two DRC exclusions that no longer match a
    violation: the U18 pad pair, keyed to a position the live violation has
    moved off, and the USB1 hole clearance, obsolete since those two pads
    became NPTH. The one remaining exclusion covers the OSD_LVL track past
    C39 pad 2.
    DRC at 0.1 mm: one error, U18 pad 2 to pad 5 at 0.09 mm, internal to
    the X2SON-6 land pattern. One warning, the non-mirrored B = SIGNAL
    stackup label. Z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
    [OpenFC.kicad_pcb]
2026-08-20 fix(lib): use KIPRJMOD for the SOD-123 3D model path
    The footprint carried an absolute /Users path, so the model resolved on one
    machine only and leaked a home directory into a public repo. Now matches
    every other footprint in lib.pretty.
2026-08-22 3D models: retarget to KiCad stock, fix placement
    Replaces easyeda2kicad 3D models with KiCad's own where a dimension-matched
    equivalent exists. The easyeda models run 20-100x denser for the same package
    and most carry the LCEDA watermark modelled as raised geometry, which renders
    on every CAD picture of the board and is not on the real part.
    Only the (model ...) reference, offset and rotation are touched. No footprint,
    pad, land pattern, net, placement or value is modified. Applied to the footprint
    LIBRARY and the boards together: fixing only the .pretty is invisible because
    each board carries its own footprint copy, and fixing only the .kicad_pcb is
    surface level because the next placemen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
    [OpenFC.kicad_pcb]
2026-08-22 Rebuild the four shared E6 substitute STEPs as solids
    Byte-identical copies of the OpenFC-Lite files, which sewed the .wrl
    meshes into shells and wrote those, so they imported as loose surfaces.
    Regenerated with the fixed wrl_to_step.py: bounding box and origin
    unchanged to 0.0000 mm, check_models reports zero E6 on this board.
2026-08-22 Replace the USB-C 3D model with a clean B-rep, 34.3 -> 0.51 MB
    The easyeda model was a 13,715-face tessellation carrying an LCEDA
    watermark. This one is a real B-rep: 34 solids, 319 faces, no watermark,
    and it drops the OpenFC-Lite board export from 37.8 to 24.8 MB.
    It is a substitute, not the same part. It has 16 signal contacts against
    the QTWT's 12, and is 0.56 mm wider and 0.45 mm deeper. Placed by
    bounding-box centre, +2.093 mm in Y, which splits the extra depth evenly:
    all 16 pins land inside the 12 pad rectangles, and the mouth clears the
    board edge by 1.50 mm against the old model's 1.27 mm. Z is unchanged,
    the two models already agreed there to 0.08 mm.
    The .wrl is regenerated fro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
2026-08-25 schematics: complete Manufacturer/MPN coverage, trim stray whitespace
    22 field fixes across blackbox, osd, power, rp2350a: Manufacturer backfilled
    from the LCSC catalogue, trailing space trimmed from four XL-1005UGC MPNs.
    pads.kicad_sch (uncommitted WIP) untouched. Part of the fab-agnostic BOM
    standardisation for quoting outside JLCPCB.
    kicad-skip reflowed the touched files; structural diff shows only property
    changes, ERC identical (163 violations before and after).
    [blackbox.kicad_sch, osd.kicad_sch, power.kicad_sch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]
2026-08-25 lib: fill LCSC, Manufacturer and MPN on placed library symbols
    Copied from the standardised schematic instances: 11 symbols gain
    missing fields, including LCSC for LP5912-1.8DRVR. DMN1150UFB-7B,
    LMR51420YDDCR and LSM6DSV16XTR left alone: their placed instances
    carry substitute parts (AP1606 C2849580, LMR51430YFDDCR C5219261,
    BMI270 C2836813), needs a human call.
2026-08-25 Rebrand silkscreen to incutec, final rev3.3 pass (Stan)
    [OpenFC.kicad_pcb]
2026-08-25 Remove RSSI/ADC2 pads that were never on the board
    Stan's pads.kicad_sch cleanup deleted the RSSI and ADC2 solder pads
    (never fitted on any built board); this completes it on the root sheet:
    the two sheet pins, their parked no-connect flags and the two orphan
    wires are removed. ERC hier_label_mismatch and no_connect_dangling now
    zero; unconnected_wire_endpoint stays at its baseline 3.
    [OpenFC.kicad_sch, pads.kicad_sch]
2026-08-25 Sync silkscreen rev text to rev3.3 (pipeline rev sync)
    [OpenFC.kicad_pcb]
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2026-08-31 AGENTS.md: sync from the bench mirror rework (#40)
    Formatting repairs plus verified corrections from the 2026-08-31 bench
    session (fact-checked against datasheets, board READMEs and firmware
    sources). Details per file in OpenDrone-Testing commit 06034b3.
2026-09-01 chore: standardize OPENFC-LITE-2020 assets and guidance
    [OpenFC.kicad_pcb]
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2026-09-24 docs: fix broken DESIGN.md link and rename stale rev2 photo files (#43)
    hardware/research/imu-selection/README.md linked to hardware/docs/DESIGN.md,
    which does not exist in this repo; the IMU footprint/compatibility
    information it pointed at actually lives in AGENTS.md. Repointed the link
    there.
    Also renamed images/openfc-lite-mini-rev2-{top,bottom}.png to
    images/{front,back}.png (matching the OpenESC-20x20/OpenESC-30x30
    convention) and updated README.md. The files were re-rendered on the
    current Rev3.3 (incutec-branded) board on 2026-08-25 but still carried the
    old rev2 name. Grepped the rest of the workspace: nothing outside this repo
    references the old filenames.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
2026-10-02 Mark the IMU research as superseded and drop supplier prices (#45)
    The research note still called the Rev 1 IMU "being replaced" while the
    README names the BMI270. Add a superseded header pointing at the README.
    Remove LCSC/DigiKey prices and stock figures (sourcing does not live in
    OpenDrone repositories); the technical comparison is unchanged.
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2026-10-25 firmware: rev3.3 image with working analog OSD and LED strip, update steps in README (#54)
    The 2026.12 image (cfg a2b6666) put the LED strip and the FB OSD on PIO2,
    where the OSD program no longer fits: no OSD while LED_STRIP is on. The LED
    pad's N-FET stage (Q6) inverts the WS2812 signal, which Betaflight did not
    handle. New image: Betaflight d593400 + betaflight/betaflight#15900, config
    OpenDrone-hw/betaflight-config 9eada21 (LED strip on PIO1, inverted output).
    Bench: rev3.3, OSD with an NTSC camera and a 64 LED WS2812 panel together.
    The 2026.6 fork image moves to firmware/archive/.
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2026-11-11 docs(rules): kicad-skip cannot round-trip KiCad 10 schematics (#58)
    Syncs the shared Rules section from OpenDrone-hw/hardware-template (PR 16).
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
